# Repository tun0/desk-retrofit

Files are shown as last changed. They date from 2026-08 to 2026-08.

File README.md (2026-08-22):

# Jysk Slangerup standing desk — smart drive retrofit

Reverse engineering notes, design decisions and firmware for replacing the
control of a **Jysk Slangerup** electric height-adjustable desk.

The original complaint: the up/down buttons switch the motor on at full
voltage, so the desk jolts into motion. The goal is soft start/stop under
programmatic control, with height presets as a later phase.

This document is the project's memory. It records not just the final design
but the measurements it rests on, the alternatives considered, and — deliberately —
the wrong turns, because several conclusions here are only correct in light of
an earlier mistake.

---

## 1. The desk as found

### 1.1 Documented facts

From the JYSK manual (rev. 1, 22.06.2022; item numbers 3601130, 3601131,
75668001, 75672001, C123681):

| Property | Value |
|---|---|
| Height range | 68–118 cm |
| Max load | 40 kg |
| Speed | ~25 mm/s, load dependent |
| Duty cycle | 10% at 50% max load, or 2 min continuous |
| Operation | Micro switches |
| Anti-collision | **Not listed** (JYSK's SVANEKE model does advertise it) |
| Manufacturer of record | 2-connect ApS, Ikast, Denmark |

Essentially nothing else is publicly documented. 2-connect is a furniture
trading and sourcing company rather than an electronics designer, so they are
the CE-responsible party and the parts are unbranded OEM. There is no control
box model number, no wiring diagram, no service manual, no aftermarket
replacement. The Machinery Directive technical file is only available to
national market-surveillance authorities, not the public.

**Conclusion: everything below was measured, not looked up.**

### 1.2 Physical layout

- **Single motor**, permanently attached to one leg, driving the second leg
  through a shaft. Both columns are mechanically locked together, so one
  position measurement is authoritative for the whole desk.
- **No separate control box.** The electronics — such as they are — live in
  the motor housing. Only two cables exist: PSU → motor housing, and a
  4-conductor cable between the motor housing and the handset.
- The handset enclosure contains two rocker microswitches and nothing else.

### 1.3 Power supply

Label reads:

```
Input:  AC 100-240V  50/60Hz  1.5A
Output: DC 29.0V  1.8A  52.2W
```

The 1.8 A rating turns out to be one of the most important numbers in the
project — see §2.4.

### 1.4 The 4-conductor cable

Terminals on the motor housing, left to right: **red, yellow, white, grey**.

| Conductor | Connects to |
|---|---|
| red | UP rocker only |
| yellow | both rockers |
| white | both rockers |
| grey | DOWN rocker only |

Two shared conductors, one unique conductor per rocker, three terminals per
rocker. That topology is the signature of **two SPDT changeover switches
sharing a common pair** — the minimal H-bridge you can build from two rockers.

### 1.5 The connector

**Molex Mini-Fit Jr., 4.20 mm pitch, 4 circuits, dual row (2x2).**

Identified by caliper, recorded here because the pitch is genuinely awkward to
measure on a moulded housing with recessed cavities, and a first attempt at
buying an extension cable got the wrong part.

Two measurements, and how they combine:

| Measurement | Value |
|---|---|
| Terminal centre-to-centre (pitch), approximate | ~4 mm |
| Outer edge to outer edge across two adjacent cavities | 7.7 mm |

The second is the reliable one — flat outside faces, a longer span, so a
smaller relative error. It equals **one pitch plus one cavity width**:

```
7.7 mm  =  4.2 (pitch)  +  3.5 (cavity)      → Mini-Fit Jr.   ✓
5.4 mm  =  3.0 (pitch)  +  2.4 (cavity)      → Micro-Fit 3.0  ✗
```

Micro-Fit was the initial guess — it is the usual choice for this class of
desk — but it cannot produce a 7.7 mm span. For reference, a Micro-Fit 3.0
dual-row 4-circuit part measures 9.65 mm along the row axis against 6.65 mm
for the 2-circuit version; the 3.00 mm difference is exactly one pitch.

Family identification by pitch, for future reference:

| Pitch | Family | Current/circuit |
|---|---|---|
| 2.00 mm | Milli-Grid | low |
| 2.50 mm | Nano-Fit | ~6.5 A |
| 3.00 mm | Micro-Fit 3.0 | 5.0 A |
| 3.50 mm | Ultra-Fit | ~9 A |
| **4.20 mm** | **Mini-Fit Jr.** | **9.0 A** |

9 A per circuit is wildly over-specified for 1.8 A — normal for a furniture
OEM buying whatever was cheap and available.

Quick sanity check without calipers: Mini-Fit Jr. *is* the ATX family. The
4-pin 12V CPU plug on any PC power supply is the same connector.

### 1.6 Pinout and polarity

Measured on the **5557 receptacle** — the half with the *movable* thumb latch,
holding female sockets. The 5559 plug has the fixed catch that latch grabs.

```
Receptacle (5557, female sockets, movable latch)
viewed INTO the mating face, latch uppermost:

        ─── latch ───
      ┌───────────────┐
      │  [ 1 ] [ 2 ]  │   motor pair
      │  [ 3 ] [ 4 ]  │   supply pair
      └───────────────┘

  1 = motor          3 = supply +
  2 = motor          4 = supply -
```

The plug, viewed into *its* mating face, is the left-right mirror of this.
Never carry a "left and right" description across from one half to the other.

> **This numbering matches Molex's own, confirmed against the real sales
> drawing (SD-5557-003, also cited in `NETLIST.md` for the symbol pin
> order).** Its "CIRCUIT SIZE LAYOUT" table shows circuits 1/2 in the row
> nearest the latch and 3/4 in the row away from it, viewed into the mating
> face with the latch uppermost — the identical reference frame and
> assignment used above. The housings themselves still carry no legible
> moulded numbers, so this was derived from the drawing's orientation
> reference, not read off the part; a pre-made cable assembly could still
> use different circuit numbers internally, so don't assume one matches
> without checking.

Even with the numbering confirmed, **mark the connector physically**: a
dab of paint or nail varnish on the MOT_A cavity. Then the
mark is the definition and no orientation reasoning is ever needed again. The
housings are polarised, so the box itself cannot be mated the wrong way round.

**Polarity, measured:**

| Applied | Result |
|---|---|
| 3→2 and 4→1 (circuit 2 positive) | **UP** |
| 3→1 and 4→2 (circuit 1 positive) | **DOWN** |

**Naming convention used throughout this project:**

> **MOT_A** is the conductor that must be **positive to raise** the desk =
> circuit 2.
> **MOT_B** = circuit 1.

Defining it this way makes the schematic correct by construction, so the only
project-specific fact to remember is which circuit MOT_A is.

**On wire colours — not needed.** The colours in §1.4 did one job: deriving
the rocker topology. Everything downstream works in circuit numbers, because
the box mates with connectors rather than cutting into the cable, so a
conductor's colour mid-run never comes up. The connector end also carries a
moulded protector sleeve, so the colours are not visible there anyway.

For the record, the mapping is *predicted* but unconfirmed: red is the UP
rocker's common and the rockers rest on NC → V+ (§2.4), so red goes negative
while raising, making **red = circuit 1 (MOT_B)** and **grey = circuit 2
(MOT_A)**. If it is ever wanted, it can be had without opening the handset:
the colours are visible at the motor housing terminals, so continuity from a
housing terminal to a connector pin gives the mapping with the cable still
installed.

**Re-identification recipe.** The numbering is a convenience, not a
dependency — every fact above is re-measurable in about five minutes with
nothing but a multimeter:

| Step | Measurement | Tells you |
|---|---|---|
| 1 | ~2.5 Ω across a pair | that pair is the motor winding |
| 2 | ~29 V across the other pair (powered) | supply pair; DC volts gives + and − |
| 3 | Park at the **bottom** stop, diode mode across the motor pair | the conductor reading ~0.6 V with the **red** probe on it is **MOT_A** (positive raises) |

Step 3 works because at the bottom stop the limit switch is open and its
bypass diode passes only the escape direction, which is up.

---

## 2. Measurements and what each proved

Every measurement below was taken with mains disconnected unless noted.

### 2.1 Which pair is which

With the handset assembly disconnected:

- ~**30 V** across one pair → these are the supply rails, routed up to the handset.
- ~**2.5 Ω** across the other pair → this is the motor winding, routed up and back.

A relay coil at 29 V would read hundreds of ohms to low kilohms. 2.5 Ω can
only be a winding. **This proved the rockers carry full motor current and that
no controller exists anywhere in the desk.**

### 2.2 Isolation

- Supply negative to either winding terminal: **< 1 V**, and **open** on the
  resistance range.
- All conductor combinations open except the 2.5 Ω winding pair.

This ruled out either winding end being permanently tied to a rail — which
would have shorted the supply on the first press of a naive H-bridge retrofit.

### 2.3 End stops

Diode mode across the winding pair, measured at the motor-side terminals:

| Position | Reading |
|---|---|
| Mid-travel | near zero both directions (the winding) |
| Bottom stop | **0.6 V one way, OL the other** |
| Top stop | same behaviour, mirrored |

This identifies **diode-bypassed limit switches** — a normally-closed
microswitch at each end of travel with a diode across it, in **series** with
the winding. At a limit the switch opens: one polarity is blocked entirely,
the other passes through the bypass diode so the desk can drive away from the
stop. Two switches, two diodes, still only two conductors down the leg.

Consequences:
- The desk cannot be driven past either extreme, in hardware, regardless of
  firmware. This is inherited for free by any retrofit.
- Homing is clean: drive down until current collapses to zero. That is the
  switch opening at a repeatable mechanical position.

### 2.4 Rest state and current

With both rockers in neutral, **three of the four contacts read shorted**, to
the **positive** rail. Both rockers sit on their NC contacts, tying both
winding ends to V+. That is dynamic braking, and it explains why the desk
stops as abruptly as it starts.

Locked-rotor current would be 29 V ÷ 2.5 Ω ≈ **11.6 A** — but the supply is
rated 1.8 A. The PSU current-limits long before the winding sees anything like
that. Practical consequences:

- The supply is already acting as the current limiter and, incidentally, as
  the collision protection. Jam the desk and it drops into limit and stalls
  rather than drawing 12 A.
- **Do not casually fit a bigger PSU.** That current limit is load-bearing
  safety on a frame with no other protection, and the motor's thermal rating
  was chosen around it.
- A sanity check supports this: lifting ~60 kg at 25 mm/s is ~15 W mechanical,
  which through a spindle drive lands near 40–50 W electrical. The desk runs
  close to the supply limit under load, which is exactly what the manual's
  "speed depends on load" is describing.

### 2.5 The as-found circuit

```
SW3 (UP rocker, SPDT):
    NC ── V+
    NO ── V−
    COM ── [LIM_top ∥ D_down] ──┐
                                 │
                                (M)
                                 │
SW4 (DOWN rocker, SPDT):         │
    NC ── V+                     │
    NO ── V−                     │
    COM ── [LIM_bot ∥ D_up] ─────┘
```

At rest both rockers sit on NC (→ V+), tying both winding ends to the
positive rail — that's the brake state. Pressing a rocker moves its COM
to NO (→ V−) instead, which is what drives the motor.

Not kept as a separate schematic file — this circuit is fully captured by
the measurements above and the diagram, and the stock wiring is unmodified
in the chosen design (§4).

---

## 3. Design evolution

Four designs were considered in sequence:

| | Design | Outcome |
|---|---|---|
| 3.1 | ESP32 + integrated H-bridge IC | rejected on voltage headroom |
| 3.2 | Relay direction + low-side FET PWM | adopted as the drive topology |
| 3.3 | In-line interceptor with 3-pole transfer relay and automatic fallback | good design, dropped as over-complex |
| 3.4 | **Simple in-line drive** | **chosen** |

> Why each of the first three lost, and what would be worth keeping if any
> were revived, is in **`APPENDIX.md` §5**. Several were reasonable at the time
> and became obsolete only when a later measurement changed the picture.

### 3.4 Simple in-line drive — **CHOSEN**

Same in-line position, no transfer relay, no automatic fallback. The board
owns the winding permanently. Reverting is physical:

```
motor — box — handset      becomes      motor — handset
```

39 components instead of 51. Dropping the transfer also deleted the clamp
diodes: with no transfer relay, 29 V can never appear on the handset
conductors, so there is no transition window to protect against.

---

## 4. The chosen design

Schematic: `desk.kicad_sch` / `.pdf`.

### 4.1 Topology

```
PSU 29V ────────┬── VSW rail
                │
                ├── buck ── +5V ── ESP32
                │
         [K1]───┴────[K2]        two SPDT relays, NC→VSW, NO→MRET
          │           │
          └─ winding ─┘      via limit switches in the leg
                │
              MRET ──[Q5]── GND    low-side PWM
                │
              [D1] freewheel to VSW
```

### 4.2 Relay truth table

`MOT_A` = circuit 2, positive to raise (§1.6). `MOT_B` = circuit 1.

| K1 | K2 | Result |
|---|---|---|
| off | off | both winding ends on VSW → **brake** (matches OEM rest state, and is the boot state) |
| **on** | off | MOT_B to return, MOT_A stays positive → **UP** |
| off | **on** | MOT_A to return, MOT_B stays positive → **DOWN** |
| on | on | both ends on MRET → coast if Q5 off, brake to ground if on |

No combination shorts the supply.

The signal chain therefore runs `DIR_A → U3 → Q3 → K1 = up` and
`DIR_B → U3 → Q4 → K2 = down` (same chip, different gate units - see
NETLIST.md), which is what `relay_up:` and `relay_down:` in
`desk.yaml` are wired to. The current sensor sits in the K1 (MOT_B) leg; either
leg works, since it only needs to be inside the freewheel loop.

### 4.3 The handset

Permanently removed from the motor circuit. The board feeds it **3.3 V** and
reads the rockers as dry contacts — high at rest through the OEM NC contact,
low when pressed. Same cable, same connectors, different job. The tactile
up/down survives alongside the screen.

### 4.4 Current sensing

An **ACS712ELCTR-05B** sits in the motor leg, *not* in the FET return (switched
from the ACS724-5AB this design used earlier — see §6.5/§6.6; same Hall-effect
family, pin-identical, chosen for real stock availability). With low-side
chopping the FET only carries current during the on-time; freewheel current
bypasses it entirely, so a low-side shunt would read a chopped fraction and
need synchronous sampling. In the motor leg the sensor is inside the freewheel
loop and reads true motor current continuously.

Its output is centred at 2.5 V, 185 mV/A (Allegro's own datasheet figure for
this exact part), reaching ~3.4 V at the full ±5 A range - over a comfortable
ADC margin, so R1/R2 (10k/20k) divide it down to a ~2.3 V max. **ISENSE must
be on ADC1** — ADC2 is unusable while WiFi is active.

### 4.5 Failsafe layer

- **Boot state.** R8/R9/R10 hold all three drive lines at "off" before firmware
  runs. These *must* sit on non-strapping GPIOs — on the classic ESP32 avoid
  GPIO0, 2, 12 and 15, since a pull resistor there fights the bootloader and
  GPIO12 pulled high selects the wrong flash voltage. The S3's strapping set
  differs; the principle holds.
- **Watchdog.** A 74HC123 retriggerable monostable (~250 ms) gates all three
  drive lines through a 74HC08. The ESP32 must keep kicking it. This sits
  **downstream of the MCU** deliberately: LEDC PWM keeps running in hardware
  after a firmware hang, so stopping PWM in software is not a safety measure.
- **Sequencing.** Relays change state only with Q5 off and current decayed
  (~50 ms). Switching contacts under a couple of amps of inductive DC is how
  relays weld, and a welded direction relay on a desk is a genuinely bad
  failure. On a watchdog trip this holds automatically: Q5 turns off in
  microseconds while relays take milliseconds to release.
- **Coast is safe.** Loss of drive leaves the desk where it is, because the
  spindle is self-locking. This is why the stock desk isn't dangerous despite
  having no electronics at all.
- **Duty cycle.** Enforce the manual's 10% / 2-minute limit in firmware.
  Thermal damage is the boring failure mode.
- **Travel timeout.** Full range is 500 mm at 25 mm/s, so anything over ~25 s
  of continuous drive is a fault.

---

## 5. Corrections made along the way

Recorded because several later conclusions only make sense in light of these.

1. **"No anti-collision implies no current sensing."** Too quick. If the desk
   had used stall detection at the end stops, it would have needed current
   sensing after all. Resolved by finding passive diode-bypassed limit
   switches — but the inference was unsound until then.
2. **Predicted the wrong diode-test result.** Expected "winding one way, diode
   the other". Wrong: the switch and its bypass sit in *series* with the
   winding, so at a limit one polarity is blocked entirely. The measured
   0.6 V / OL is what the series arrangement predicts.
3. **Recommended BTS7960 / VNH5019 on current headroom alone.** Both are out
   of voltage spec at 29 V (BTS7960: 5.5–27.5 V; VNH5019: 5.5–24 V). They
   survive 40 V+ as absolute maximum, but "probably fine" is not what should
   be holding up a desk.
4. **"Size the bridge for 12 A stall."** Wrong — the PSU current-limits at
   1.8 A, so the winding never sees locked-rotor current. This also reframed
   the supply as the existing collision protection.
5. **"Losing brake removes protection."** Overstated, and inconsistent with
   the self-locking spindle noted elsewhere. The brake does stop-precision
   work, not safety work.
6. **Wired NC to V− in the first `desk_original` schematic.** The measurement
   (three contacts shorted, to the positive rail) says NC → V+. Caught only
   when the netlist was rendered as a connectivity graph; the written note and
   the drawing had disagreed silently.
7. **Ran literal power rails across the schematic sheet.** Intended to remove
   "islands"; produced a picket fence of metre-long ground verticals instead.
   Local GND and rail symbols are the conventional idiom precisely because
   they avoid this. The real problem was that *signals* were labelled rather
   than wired.
8. **Planned an "ESP32 devkit + display" (CYD).** This board lives under the
   desk, not somewhere a display is ever seen, so U1 is a bare
   ESP32-S3-DevKitC instead. A display, if ever wanted, would be a separate
   peripheral mounted on the desk itself, not part of this board.
9. **Specified Q5 as IRLB8721.** Caught by an external review, not by this
   project's own process — the schematic still had it after the part was
   supposedly already swapped. IRLB8721's 30 V VDSS doesn't clear the 29–30 V
   rail once flyback clamping is accounted for; fixed to IRLZ44N (55 V). See
   §6.2.
10. **Assumed hand-wired perfboard was the assembly plan.** Reasoning at the
    time: this design is all through-hole specifically because there's no
    reflow equipment, and a fab-house PCB order felt like overkill for a
    one-off — so point-to-point perfboard wiring, guided by a generated
    wiring table, looked like the natural fit. Reversed once that wiring
    table turned out to need far more jumpers than expected, concentrated
    around locally dense ICs rather than anything structural — a strong
    signal that hand-wiring reliability, not layout, was the actual risk.
    A real 2-layer board (still hand-soldered, still through-hole — see
    §6.5) routes those same nets with zero jumpers once an autorouter can
    place traces on both layers, so it was worth doing even without a
    fab-house order: milled at home from a standard 70×100mm pre-cut
    copper-clad blank instead of ordered or hand-wired. See
    `schematics/desk.kicad_pcb` and its commit history for the design
    itself.

---

## 6. Bill of materials

Rough EUR incl. BTW, Netherlands. Prices are budgeting figures, not quotes.

| Item | Note | Cost |
|---|---|---|
| ESP32-S3-DevKitC | bare devkit, no display — see §5 | €5–15 |
| 2x SRD-05VDC-SL-C relay | bare relay, not a driver-included module — this design drives the coil directly, see NETLIST.md Drive section | €3–5 |
| 2x 2N7000 MOSFET | relay coil drivers (Q3/Q4), TO-92 — through-hole | €1–2 |
| IRLZ44N MOSFET | logic-level, 55V — see §6.2 | €1–2 |
| BC337 + BC327 | discrete gate driver push-pull — see §6.2 | €1–2 |
| 74HC123 + 74HC08 | watchdog and gating | €1–3 |
| SB560 Schottky | freewheel | <€1 |
| 2x 1N4148 | relay coil flyback diodes (D2/D3), DO-35 | <€1 |
| ACS712ELCTR-05B (bare) + SOIC-8→DIP-8 adapter | bidirectional, 5A — see §4.4/§6.5; switched from the ACS724xLCTR-05AB this design used earlier for real stock availability (pin-identical, see §6.6); the Pololu carrier is dropped either way, its 2 caps (C2/C3) now on the main board instead; or 10 mΩ shunt + INA240, similar cost | €2–5 |
| LM2576HVS-5.0 buck | **must** be the true HV variant (60V input) — see §6.1/§6.5; SMD (TO-263-5), not the THT part this design used earlier, which proved unsourceable at hobbyist quantities | €6–9 |
| TVS 33 V bidirectional | D4 — no fuse fitted, see §6.1 | <€1 |
| Passives | resistors, caps | €4–8 |
| 4x 2-position screw terminal | 2.54mm pitch, board-side termination (TB1, TB2, TB4, TB5) — see §6.4 | €2–4 |
| Mini-Fit Jr. housings + terminals | 2 mating pairs, each now on a short pigtail off the board rather than a board-mount connector — see §6.4 | €3–6 |
| PCB blank, 70×100mm pre-cut copper-clad (2-layer) | milled, not fab-house ordered — see §6.5; SHOPPING_LIST.md flags this as still needing a specific supplier | €5–10 |
| **Total** | | **€25–100** |

Phase 2 adds ~€15–25 for a VL53L1X carrier and bracket. Sourcing detail
below (§6.6).

### 6.1 Voltage, not current, is the constraint

The rail is 29 V nominal, 30 V unloaded. Anything in the motor path or the
buck input needs headroom above that. Common traps:

- BTS7960 / IBT-2: spec'd 5.5–27.5 V. Out of spec.
- VNH5019: 5.5–24 V. Out of spec.
- MP1584 / Mini-360 buck modules: top out ~28 V. Marginal at best.

No fuse is fitted (there was one in early drafts, `F1`). The wall supply
already current-limits at 1.8 A — that limit is this design's only collision
protection, already relied on elsewhere (§4.4, `CLAUDE.md`'s own hard
invariants) — so a fuse adds little on top of it while being one more
embedded part to replace if it ever blows. The OEM desk never had one
either. D4 (33 V bidirectional TVS) stays.

### 6.2 Q5: voltage rating first, then the gate driver

**Q5 is IRLZ44N (55 V), not IRLB8721 (30 V).** The IRLB8721 is a common
default for "logic-level MOSFET," but its 30 V VDSS doesn't clear this
29 V nominal / 30 V unloaded rail — at PWM turn-off the freewheel diode
clamps the drain to VSW plus a diode drop, putting it at or over absolute
maximum every cycle. Substitution criterion for any replacement: check
**Qg and VDSS**, not Vgs(th) — plenty of parts marketed as "logic-level"
still top out at 30 V.

The gate driver still isn't optional: at 3.3 V Vgs a logic-level MOSFET is
only partially enhanced, and at 20 kHz that's how you cook a part that
would otherwise dissipate under 0.1 W. This design drives Q5 from a
discrete BC337/BC327 push-pull (not an IC — see `schematics/gen/symbols.py`),
fed 5 V through the AND gate output. Avoid the ubiquitous IRF520 "MOSFET
trigger" modules — that FET isn't logic-level at all.

### 6.3 K1/K2 are bare relays, not a driver-included module

**This design drives the coil directly** (Q3/Q4 discrete transistor
switches, D2/D3 flyback diodes — see NETLIST.md's Drive section), not
through a prebuilt "2-channel relay module" board. Those Arduino-kit
modules already include their own opto-isolated input, driver transistor
and flyback diode, which would make Q3/Q4/D2/D3 redundant rather than
complementary if one were used here — don't substitute one in without
also removing this board's own driver circuit. What to check when buying
the bare relay itself:

- **Coil voltage** — must be 5 V; this design's coil drive assumes it, and
  a 12 V coil would draw roughly half the current for the same drive
  voltage, undersaturating the relay.
- **Contact rating** — typically 10 A 250 VAC / 10 A 30 VDC. Your 29 V is right
  at that DC limit; acceptable only because contacts are cold-switched
  (§Sequencing/hard invariants — relays only change state with the FET
  off and current decayed).
- **Pinout** — EN50005/"Form C" (the real Kicad symbol this design uses,
  `Relay_SPDT`) is the common footprint for this class of relay; verify
  before assuming a drop-in substitute matches pin-for-pin.

### 6.4 Connector parts (Mini-Fit Jr., 4 circuit dual row)

| Part | Molex no. | Legacy |
|---|---|---|
| Receptacle housing (holds female terminals) | `39-01-2040` | 5557-04R |
| Plug housing (holds male terminals) | 5559 series, 4-circuit | 5559-04P |
| Female crimp terminal | 5556 | |
| Male crimp terminal | 5558 | |

**Wire-to-wire pairs a 5557 receptacle with a 5559 plug.** Datasheets for the
5557 list 5566 and 5569 as mating housings — those are *PCB headers*, not the
wire-to-wire half. That is the most likely explanation for the first wrong
order, alongside Molex's naming: a "receptacle housing" holds female terminals
while a "plug housing" holds male pins, and the plug is the part that inserts
into the receptacle. Order by the terminals, not by the shape you are looking
at, and check the datasheet drawing.

The retrofit box needs a **5559 plug on one end and a 5557 receptacle on the
other**, so it drops into the existing cable run in only one orientation.

Make up a short 5557-to-5559 **coupler** at the same time and tape it inside
the leg. That is the one-minute revert, and it is worth doing while the parts
and crimp tool are already on the bench rather than at an awkward moment.

Because this is the ATX family, a PC 4-pin 12V CPU extension is mechanically
correct and costs a few euros. Two cautions: verify the pinout is
straight-through 1:1 rather than crossed, and PC cables use stiff 18 AWG that
may not sit well in a desk-sized strain relief. Crimping your own in 20 or
22 AWG gives a tidier result; 2 m at 1.8 A is a couple of hundred millivolts
round trip either way.

Build any extension by **matching wire colours end to end** rather than
trusting circuit numbering. One reversed pair swaps the rails.

**The board itself doesn't carry a Mini-Fit connector at all.** Each side
(motor housing, handset) terminates on the board in a 2-position screw
terminal instead (TB1, TB2, TB4, TB5 — 2.54mm pitch, solders straight onto perfboard,
no crimp tool needed for board assembly). A short pigtail, crimped
separately on the bench, carries each pair from its screw terminal to the
actual Mini-Fit half (still needed, still built exactly as described
above) that mates with the cable. One extra connection point per circuit
versus terminating the Mini-Fit directly at the board edge, traded for
never needing a crimp tool during board assembly or rework.

### 6.5 This design is deliberately all through-hole

A hand-soldered, self-milled 2-layer PCB (`schematics/desk.kicad_pcb`,
sized to a standard 70×100mm pre-cut blank), not a fab-house order and not
raw perfboard either — but the reason for through-hole-only still holds
regardless of which of those three it ends up being: no reflow equipment.
Every substitution should preserve that, not just match electrically.
Substitution criterion is the **package**, not just the part:

| Part | Through-hole option |
|---|---|
| 74HC123 | `74HC123N` / `SN74HC123N`, DIP-16, socketed |
| 74HC08 | `SN74HC08N`, DIP-14, socketed |
| BC337 / BC327 | TO-92 (already through-hole) |
| IRLZ44N | TO-220 |
| 2N7000 | TO-92 |
| SB560 | DO-201AD axial |
| TVS 33 V | `P6KE33CA` or `1.5KE33CA`, axial |
| Coil flyback | `1N4148`, DO-35 |
| SRD-05VDC-SL-C relay | bare relay, TO-5-ish THT (EN50005/Form C) |
| ACS712 | bare SOIC-8 chip on a generic SOIC-8→DIP-8 adapter, socketed like U1 |
| ESP32-S3-DevKitC | devkit module, socketed with 0.1" pin headers |

Every DIP part on this board is socketed, not just U1/U4 as originally
planned - noticed missing from the shopping list only after seeing a
render (see conversation), added for all of U2/U4/U3 once caught. Worth
it specifically because this board is hand-milled, not a plated-through-
hole fab board - pads are more fragile under a desoldering mistake here
than on a normal PCB, and sockets cost pennies.

**U5 (buck regulator) is the one deliberate exception.** The true
through-hole HV buck (`LM2596HVT`/`LM2576HVT`, TO-220-5) turned out to not
practically exist at hobbyist quantities anywhere checked — Reichelt, TME,
Mouser, Farnell direct, and Farnell-via-sinuss.nl all came up empty or
unconfirmed for the T-suffix part specifically (see conversation). The
real, in-stock option is `LM2576HVS-5.0/NOPB`, S-suffix, **TO-263-5 SMD**.
This doesn't violate the "no reflow" reasoning, though: TO-263-5 is 5
large gull-wing leads at roughly TO-220 pitch plus a thermal tab, one of
the more hand-solder-friendly SMD packages that exists — no hot air or
reflow needed, just a bit more dwell time on the tab. Checked directly
against TI's own datasheet: TO-220-5 and TO-263-5 share an identical pin
table, so this was a footprint-only change, no rewiring.

ACS712 (`ACS712ELCTR-05B`, §4.4) is SOIC-8, not through-hole itself — what
keeps the board through-hole is whatever it's mounted on, same reasoning
as U1. This design used the ACS724xLCTR-05AB before switching to ACS712
(same Hall-effect family, verified pin-identical against both datasheets
directly, pin-for-pin — not assumed from the similar part number or a
misleadingly-named KiCad library symbol, see conversation) purely because
the ACS724 bare chip proved nearly unsourceable, while ACS712ELCTR-05B is
in real stock at three-plus suppliers already in rotation for this
project. Either way, mounting the bare chip on a generic SOIC-8-to-DIP-8
adapter (0.3"/7.62mm row spacing, already in inventory) instead of a
ready-made carrier (Pololu, in this design's earlier revisions) drops two
things that carrier provided for free: a 0.1uF VCC bypass cap and a 1nF
FILTER-to-GND cap, both confirmed against Allegro's own ACS712/ACS724
application circuit (identical circuit on both parts' datasheets, not
just the Pololu board). Both are now discrete parts on the main schematic
instead (C2, C3) - see NETLIST.md.

### 6.6 Sourcing (Netherlands)

Ruled out, with reasons, so they are not re-evaluated:

- **Digikey** — ~€25 shipping on small orders.
- **Farnell direct** — private-customer orders need a write-in request
  (email/fax/post) and prepayment, not normal checkout, on top of the €50
  minimum. **sinuss.nl** is a live, working Farnell/element14 private
  reseller for NL/BE (confirmed directly, unlike muxtronics.nl's own
  Farnell-intermediary service, which is dead) — usable if a Farnell-only
  part is unavoidable, but at a real price premium (30–50%+ over Farnell's
  own business pricing, confirmed directly) - not worth it for anything
  also stocked at Reichelt/TME.

Working pattern, per actual checked availability (see conversation for
the full supplier-by-supplier matrix):

- **Reichelt** — jellybeans and basic semis: resistors, caps, diodes
  (1N4148, SB560, TVS), 2N7000, IRLZ44N, `74HC123N` (also at Mouser and
  Farnell direct - TME is the actual outlier here, not Reichelt), screw
  terminals.
- **TME** — `SN74HC08N`; the `LM2576HVS-5.0/NOPB` SMD buck (§6.5 - the
  through-hole HV buck isn't practically available anywhere at hobbyist
  quantities); the SRD-05VDC-SL-C's real named equivalent, Omron
  `G5LE-1-5VDC` (5V coil, SPDT/Form-C, 10A/250VAC-30VDC — exact spec
  match, the bare Songle part itself is a module-market item most proper
  distributors don't stock discretely); and `ACS712ELCTR-05B` — confirmed
  in stock by hand after automated checks kept giving contradictory
  stock figures for it. Between this and the buck/relay, TME covers
  enough that **Mouser isn't needed at all** for the current design.
- **Modules** (ESP32 devkit, etc.) — TinyTronics (Ede), Kiwi Electronics,
  Opencircuit (Zaandam) or Antratek.
- **PCB blank** (70×100mm copper-clad) — not found at any of the above;
  expect to need a hobby/eBay/AliExpress source, as originally
  anticipated.

Substitutes worth recording:

- **IRLZ44N** → any 55–60 V logic-level N-channel in TO-220. Check **Qg and
  VDSS**, not Vgs(th) — see §6.2.
- **74HC08** → 74HC00 with inverted logic, or 74HC11 triple 3-input AND.
- **ACS712** → 10 mΩ shunt + INA240 (in the motor leg, not the FET return -
  same reasoning as §4.4), but INA240 is SOIC-8 and needs a breakout too -
  same treatment as ACS712 itself (§6.5), not a way to avoid one.

---

## 7. Firmware

ESPHome, with motion control in a custom external component.

Pure YAML cannot do this safely. Three reasons, all in the safety path:

- The watchdog kick must come from the control loop, not a timer. ESPHome's
  `interval` runs in the cooperative main loop, which WiFi work can stall for
  hundreds of ms. Solving that with a hardware LEDC pulse is worse — it keeps
  kicking through a hang, making the monostable decorative.
- Relay sequencing is a small state machine with real timing constraints.
- `adc` sensors poll on the order of seconds. Useless for collision detection.

What ESPHome earns: OTA, logging, web server, Home Assistant integration, and
LVGL for the screen. Inheriting `cover::Cover` makes the desk a first-class HA
entity with open/close/stop/position and no glue.

### 7.1 Structure

```
config/
  desk.yaml
  my_components/
    desk/
      __init__.py      (empty)
      cover.py         config schema + codegen
      desk_cover.h
      desk_cover.cpp
```

`cover.py` declares the YAML keys and emits C++ setter calls into the
generated `main.cpp`. Anything configurable goes there; anything fast goes in
the `.cpp`.

### 7.2 Control loop

A FreeRTOS task pinned to **core 0**, ticking at 200 Hz via `vTaskDelayUntil`.
WiFi lives on core 1 and cannot stall it. Each tick reads current, runs the
state machine, updates PWM duty, and *then* kicks the watchdog — after a
completed iteration, never on a timer.

States: `IDLE → SETTLING → RAMPING → RUNNING → STOPPING → IDLE`, plus a latched
`FAULT`. Relay writes are legal in `IDLE` only, and every direction change
routes through `SETTLING`. Enforcing that structurally is what stops a future
refactor quietly switching a relay under load.

Starting parameters: 20 kHz PWM, 500 ms ramp up, 300 ms ramp down, 50 ms
settle. Tune the ramps by feel.

### 7.3 To fill in

- `read_current_()` is implemented (both IDF 4.x `adc1_get_raw` and 5.x
  `adc_oneshot_read` paths, selected via `ESP_IDF_VERSION` - see
  `desk_cover.cpp`), but not yet compiled or flash-tested against real
  hardware. Why the YAML specifies `esp-idf` rather than Arduino at all:
  ESPHome's `adc` sensor is far too slow for a 200 Hz control loop.
- Relay `inverted:` flags follow this board's own direct-drive polarity
  (AND-gate through the 2N7000 coil drivers — see §6.3/NETLIST.md's Drive
  section), fixed by this design, not something a swappable module would
  determine.

**Flash with the motor unplugged first.** Watch the log and the current sensor
before anything can move.

---

## 8. Phase 2 — position feedback and presets

Phase 1 deliberately has no absolute position sensing. Presets need it.

> Full option analysis, including mounting constraints, range limits and the
> approaches that will not work, is in **`APPENDIX.md` §2**. The summary below is
> the decision, not the reasoning.

### 8.1 Direction

Leading candidate is a **VL53L1X time-of-flight sensor** aimed at the fixed
foot plate. Absolute encoding is not worth paying for, because the bottom
limit switch already gives a repeatable mechanical reference detected by
current collapse — one trip down re-homes the desk.

> Full analysis — mounting constraints, the range limit that could sink it,
> incremental optical and magnetic alternatives, commutator ripple counting,
> and why an IMU cannot do this — is in **`APPENDIX.md` §2**.

**Board prep done now, ahead of the actual build (see conversation):**
SDA/SCL break out to a real connector, `TB3`, a 5th screw terminal of the
same type as TB1, TB2, TB4, TB5, fully routed and DRC-clean. +3V3/GND for the sensor
don't get their own terminal - land a second wire under each of `TB2`'s
own two screws instead (it already carries +3V3/GND to the handset; check
that this terminal's rising-clamp accepts two wires per screw before
counting on it - a dedicated second terminal, `TB6`, was tried and
dropped once TB2-sharing made it unnecessary).

**SDA/SCL are on GPIO38/GPIO41, not GPIO12/GPIO13.** The original choice
(physical pins 18/19 on U1's footprint) turned out to sit in a part of the
board that's already at real copper capacity - neither Freerouting nor
careful manual routing could get a single track out from there, regardless
of where TB3 sat. GPIO38/41 (physical pins 35/38) sit immediately next to
DIR_A/DIR_B/PWM (pins 36/37/39), GPIOs that already route successfully
from that same neighborhood - moving to them, and relocating TB3 close by
(rotated 90° to fit the only free space in that corner), routed cleanly on
the first attempt after that. Neither is strapping/PSRAM-reserved/native-
USB, same constraints as the original choice. Firmware should target
GPIO38 (SDA) and GPIO41 (SCL) for this reason - not the GPIO12/13 an
earlier version of this section named.

### 8.2 Data worth logging from day one

Current against time for a full travel in each direction, and coast distance
after cutoff at various speeds. That's exactly the calibration data phase 2
needs, and you get it free by using the desk. If commutator ripple turns out
to be cleanly visible on the current-sense trace, the cheapest option may be
the one already built.

---

## 9. Open questions

- Exact position of the limit switches inside the leg is inferred from
  behaviour; the leg was never opened.
- The polarity convention at each limit (which probe orientation gave 0.6 V)
  was not written down. Two-minute remeasure, needed before wiring the relays
  so "up" is actually up.
- Wire colour to circuit number is predicted but unconfirmed (§1.6), and is
  **not required** for the build — noted only for completeness.
- Which of yellow / white is supply positive was never recorded. Also not
  required: circuits 3 and 4 are identified on the connector itself.
- The housings carry no legible moulded circuit numbers, but §1.6's numbering
  is now confirmed against Molex's own SD-5557-003 drawing, not just this
  file. Still worth marking the MOT_A cavity with paint so the physical part
  carries the convention directly, rather than requiring a lookup.
- ERC has been run (`kicad-cli sch erc`): 127 violations, all triaged as
  either documented gaps (unused MCU pins, U2/U3 spare units, SDA/SCL
  pending Phase 2) or artefacts of this design's power-flag/embedded-symbol
  conventions — no structural defects found.

---

## 10. Files

| File | Purpose |
|---|---|
| `APPENDIX.md` | Background, rejected alternatives, phase-2 analysis — not required to build |
| `CLAUDE.md` | Project context for Claude Code |
| `SHOPPING_LIST.md` | Purchase-ready BOM, grouped by supplier — see §6 for the narrative version |
| `schematics/desk.kicad_sch` / `.pdf` / `.svg` | **The chosen schematic design** |
| `schematics/desk.kicad_pcb` | **The chosen PCB layout** — 70×100mm, 2-layer, hand-milled (§6.5) |
| `schematics/NETLIST.md` | Connectivity reference, generated + annotated |
| `schematics/gen/` | Generator and its dependencies — see `CLAUDE.md` |
| `enclosure/shell.scad` / `.stl` | 3D-printable enclosure (single open-bottom shell) — component clearance is an estimate, see the file's own header comment |
| `my_components/desk/` | ESPHome external component |
| `desk.yaml` | Example ESPHome config |

Schematics are KiCad 7 format (`version 20230121`); KiCad 7, 8 and 9 open them.
Symbols are embedded (either hand-drawn or copied from real KiCad libraries),
so there are no external library dependencies at open-time. Regenerate with
`cd schematics/gen && make` (or `python3 sch.py`, then
`kicad-cli sch export pdf ../desk.kicad_sch`).

---

## 11. Safety notes

- Mains lives in the PSU. All work here is on the 29 V side. Do not open the
  supply.
- 29 V will not hurt you, but a dead short across it will make a mess. The
  supply can deliver 1.8 A continuously and rather more from its output
  capacitance.
- The spindle is self-locking and holds the load unpowered. This is what makes
  coast an acceptable failure mode, and it is the single assumption most worth
  re-verifying if the frame is ever changed.
- The 1.8 A supply limit is part of the safety story on a desk with no
  anti-collision. Replacing the PSU with something beefier removes protection
  the design depends on.

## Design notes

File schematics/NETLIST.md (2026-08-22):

# desk — schematic as text

Generated from KiCad's own netlist export (`kicad-cli sch export netlist`)
against the current `desk.kicad_sch`, so this reflects actual
connectivity, not the Python source. Regenerate the raw connection list (and
diff it against a saved copy, or another variant) with:

```sh
cd schematics && python3 sch.py && python3 netlist_text.py desk.kicad_sch
```

This document adds functional descriptions on top of that raw list. Kept as
a reference for understanding the circuit or rebuilding it by hand — not a
substitute for `sch.py`, which is the actual source of truth.

## Components

| Ref | Value | Notes |
|---|---|---|
| PS1 | 29V 1.8A 52W (via motor housing) | wall supply, current-limiting |
| D4 | 33V bidir | TVS, input transient protection; no fuse fitted, see README 6.1 |
| C4 | 220u 50V | input bulk cap |
| U5 | LM2576HVS-5.0 29V-5V | buck regulator, SMD (TO-263-5) - the true through-hole HV part wasn't sourceable, see README 6.5; real part is base symbol LM2596T-12, a pin-compatible non-HV placeholder for the library's own missing HV/SMD variant, see TODO.md |
| C5 | 220u 10V | +5V output cap |
| TB4 | motor pair | 2-position screw terminal; board-side termination for MOT_A/MOT_B, pigtails to J3 via J2 (no longer drawn - see Connectors) |
| TB5 | supply pair | 2-position screw terminal; board-side termination for VSW/GND, pigtails to J3 via J2 |
| TB1 | signal pair | 2-position screw terminal; board-side termination for HND_A/HND_B, pigtails to J4 via J1 |
| TB2 | power pair | 2-position screw terminal; board-side termination for +3V3/GND, pigtails to J4 via J1 |
| TB3 | ToF signal pair | 2-position screw terminal; SDA/GPIO38 and SCL/GPIO41 breakout for a future VL53L1X (Phase 2, not started - see README 8). Fully routed and DRC-clean - originally targeted GPIO12/13, moved after those pins proved unroutable, see README 8.1. +3V3/GND for the same sensor share TB2 (a second wire under each of its screws) rather than a dedicated terminal - a `TB6` for that was tried and dropped once TB2-sharing made it unnecessary. |
| U1 | ESP32 | bare devkit, no display - see README 5/6; real part is Espressif's ESP32-S3-DevKitC symbol (vendored, see Controller section) as the closest local match |
| R3 | 4k7 | HND_A series resistor (rocker divider) |
| R5 | 100k | SW_UP pull-up to +3V3 |
| R4 | 4k7 | HND_B series resistor (rocker divider) |
| R6 | 100k | SW_DN pull-up to +3V3 |
| U2 | 74HC123 250ms | monostable (retriggerable watchdog timer); real part is 74LS123, `74HC123` is a same-pinout wrapper in Kicad's library |
| R7 | 100k | U2 timing resistor |
| C1 | 2u2 | U2 timing capacitor |
| U3 | 74HC08 | triple AND gate (3 of 4 gates used); real part is 74LS08 placeholder, see TODO.md |
| R8 | 10k | DIR_A gate pulldown (boot-safe) |
| R9 | 10k | DIR_B gate pulldown (boot-safe) |
| R10 | 10k | PWM gate pulldown (boot-safe) |
| Q1 | BC337 | gate driver for Q5, NPN half of a discrete push-pull (replaces a TC4427 IC) |
| Q2 | BC327 | gate driver for Q5, PNP half of the push-pull |
| R11 | 1k | Q1/Q2 base resistor |
| Q5 | IRLZ44N | main PWM FET, low side |
| D1 | SB560 | freewheel diode |
| K1 | energized = UP (raises desk) | relay, real part Relay_SPDT (EN50005 pinout) |
| K2 | energized = DOWN (lowers desk) | relay, same part as K1 |
| D2 | flyback | K1 coil flyback diode |
| D3 | flyback | K2 coil flyback diode |
| Q3 | 2N7000 | K1 coil driver |
| Q4 | 2N7000 | K2 coil driver |
| U4 | ACS712ELCTR-05B | current sensor, in series with K1's leg; switched from ACS724xLCTR-05AB for real stock availability, checked pin-identical against both datasheets - see README 6.5/6.6. The library symbol used is literally named after this part now, no "extends" placeholder needed |
| R1 | 10k | ISENSE divider, top |
| R2 | 20k | ISENSE divider, bottom |
| SW1 | top limit | limit switch, in the leg |
| SW2 | bottom limit | limit switch, in the leg |
| D5 | allows down | SW1 bypass diode |
| D6 | allows up | SW2 bypass diode |
| M1 | 2R5 winding | motor |

## Power

Each rail is drawn as many separate flag symbols (one per tap point), not one
continuous wire — they still form a single real net each, because the
GND/rail symbols are flagged as Kicad power symbols (`(power global)`); see
`schlib.py`'s `Sym` docstring if adapting this pattern elsewhere. Confirmed
against Kicad's own netlist export, which merges them into one named net
each:

- **VSW**: D1.1, K1.12, K2.12 — the raw supply rail via the two relays' NC
  contacts and D1's anode. TB5/D4/C4/U5.1 sit on a separate, unnamed net
  (same potential, reached only through the literal-wire chain below, not
  through a VSW-flagged tap) - see Supply.
- **+5V**: C5.1, D2.1, D3.1, K1.A2, K2.A2, Q1.1, R7.1, U5.2, U5.4, U1.21,
  U2.16, U2.2, U2.3, U4.8, U3.14 — regulated 5V, from U5's OUT (pin 2) and
  FB (pin 4, tied to OUT - see Drive/Supply below)
- **+3V3**: R5.1, R6.1, TB2.1, U1.1, U1.2 — from the ESP32 board's own
  regulator (real part has two physical 3V3 pins, merged onto one net by
  Kicad's power-symbol matching even though only pin 1 is wired), not
  generated on this board; only fed out to the handset (via TB2/J1/J4) and
  the rocker pull-ups. TB2 is also the planned physical source for a
  future ToF sensor's +3V3/GND (second wire under each of its screws,
  not a separate net or terminal - see README 8.1)
- **GND**: C4.2, C5.2, C1.1, D4.2, PS1.2, Q5.3, Q3.3, Q4.3, Q2.1, R8.2, R9.2,
  R2.2, R10.2, TB5.2, TB2.2, U5.3, U5.5, U1.22, U1.23, U1.24, U1.44, U2.8,
  U4.5, U3.7

## Connectors

The board itself no longer carries a Mini-Fit Jr connector at all - see
"screw terminals" below. J3/J4 remain: both Molex Mini-Fit Jr, 4 circuit
dual row (README 1.5). Real part: Kicad's `Conn_02x02_Top_Bottom` -
row-major numbering (pins 1,2 = row 1; pins 3,4 = row 2), confirmed against
Molex's own 5557-series sales drawing (SD-5557-003).

- **J3** (in motor housing): the actual mating half for the motor housing
  cable. Wired directly to the LEG section's own motor leads and to PS1,
  not to a same-named-label match - see the note at the end of this
  document. Mates with a short pigtail off TB4/TB5 (see below), not with a
  second Mini-Fit drawn on this sheet.
- **J4** (in handset): the actual mating half for the handset cable, wired
  directly to SW3/SW4. Mates with a short pigtail off TB1/TB2.

## Screw terminals (board-side termination)

TB1, TB2, TB4, TB5 replace what used to be two board-side Mini-Fit Jr connectors
(J2, J1) - the board now only ever solders to a screw terminal (no crimp
tool needed for board assembly); a short crimped pigtail, off-board,
carries each circuit on from there to J3/J4's actual Mini-Fit pins. Real
part: Kicad's `Screw_Terminal_01x02`, 2-position, 2.54mm pitch.

- **TB4** (motor pair): 1=`MOT_A`, 2=`MOT_B` (also U4.1, U4.2 - IP+, both
  leads; K2.11 on pin 1). Circuit numbering here still matches what the
  former J2 used (README 1.6: motor pair = circuits 1/2). Which of
  MOT_A/MOT_B sits on pin 1 vs 2 is still provisional - MOT_A is defined
  by function (§1.6: whichever conductor raises the desk), not by a fixed
  pin, so if bring-up shows this backwards, relabel here rather than
  rewire.
- **TB5** (supply pair): 1=the unnamed VSW-potential net (see Power), 2=GND.
  Mirrored (pins face right, toward the SUPPLY chain) rather than left
  (toward TB4) - see `sch.py`.
- **TB1** (signal pair): 1=`HND_A` (also R3.2), 2=`HND_B` (also R4.2). No
  README-documented circuit numbering exists here (unlike TB4) - this
  assignment is for routing convenience only.
- **TB2** (power pair): 1=`+3V3`, 2=GND. Mirrored, same reasoning as TB5.

## Controller (U1 = ESP32)

Real part: Kicad's `ESP32-S3-DevKitC` (github.com/espressif/kicad-libraries,
CC-BY-SA 4.0 - vendored in `espressif.kicad_sym`, not part of the local Kicad
install). Bare devkit, no display - this hardware lives under the desk, not
somewhere a display is ever seen (README 5); a display, if ever added, would
be a separate on-desk peripheral. Chosen over `Arduino_Nano_ESP32` for its
bare GPIO-numbered pins, matching how this design already refers to every
signal (the Nano's exposed pins don't even overlap with the GPIOs this
design uses).

GPIO choice was picked for schematic-wiring simplicity, not final PCB
routing - expect this table to change once routing is considered. Only
constraints respected: avoid strapping (GPIO 0/3/45/46), avoid this specific
module's flash/PSRAM-reserved range (GPIO 22-37 - wider than the usual 26-32
since this is an N16R8/octal-PSRAM part), avoid native USB (GPIO 19/20), keep
ISENSE on an ADC1-capable pin (GPIO1-10; ADC2 and WiFi can coexist on the S3
unlike the classic ESP32, but ADC1 is still simpler).

| U1 pin | GPIO | Net | Goes to |
|---|---|---|---|
| 21 | (5V) | +5V | supply |
| 22 | (GND) | GND | ground (1 of 4 GND pins, only this one wired) |
| 1/2 | (3V3) | +3V3 | source for TB2/handset feed (2 physical pins, 1 wired, merged by Kicad's power matching) |
| 10 | GPIO17 | DIR_A | R8.1, U3.2 (gate A input) |
| 11 | GPIO18 | DIR_B | R9.1, U3.5 (gate B input) |
| 27 | GPIO21 | PWM | R10.1, U3.10 (gate C input) |
| 12 | GPIO8 | MODE | unconnected (spare) |
| 41 | GPIO1 | KICK | U2.1 (monostable A trigger input) |
| 40 | GPIO2 | ISENSE | R1.1, R2.2 (divider midpoint) |
| 18 | GPIO12 | - | unconnected (spare) - was SDA, moved off this pin, see below |
| 19 | GPIO13 | - | unconnected (spare) - was SCL, moved off this pin, see below |
| 35 | GPIO38 | SDA | TB3.1 (ToF prep, Phase 2 not started) - fully routed, see README 8.1 |
| 38 | GPIO41 | SCL | TB3.2 (ToF prep, Phase 2 not started) - fully routed, see README 8.1 |
| 15 | GPIO9 | SW_UP | R3.1, R5.2 |
| 16 | GPIO10 | SW_DN | R4.1, R6.2 |

DIR_A/PWM (GPIO17/21) aren't the classic-ESP32 assignment this design used to
use (GPIO21/27) - swapped so DIR_A, whose gate target is the topmost of the
three AND gates below, lands on the topmost of these three MCU pins, and PWM
(bottommost gate) lands on the bottommost; DIR_B (middle gate) was already in
between. The other ~30 pins on this real part (GPIO4-7, most of the JTAG/UART
pins, etc.) are unconnected - normal for a full-featured real MCU symbol
where a given design only uses a fraction of the breakout, not a sign of
anything missing. `CHIP_PU` (pin 3, the board's own EN) is also left
unconnected - it has an onboard pull-up on real devkits, no external drive
needed.

Rocker dividers: `HND_A` → R3 (4k7) → node also pulled to +3V3 through R5
(100k) → `SW_UP`. Same pattern for `HND_B`/R4/R6/`SW_DN`. Dry contacts, no
clamp diodes (29V can never reach these conductors).

## Watchdog + gating (U2 = 74HC123, U3 = 74HC08)

- U2 pin 1 (A, trigger) ← `KICK` (U1.41, GPIO1)
- U2 pin 2 (B) and pin 3 (Clr) both tied to +5V (never retriggers or clears
  from those inputs)
- U2 pins 14/15 (Cext/RCext) ↔ C1 (2u2) / R7 (100k) — sets the ~250ms pulse
  width
- U2 pin 13 (Q, watchdog output) → `WDOG` net → U3 pins 1, 4, 9 (the "A"
  input of each of the three AND gates)
- U2 pin 4 (~Q) — unconnected
- U2 pins 16/8 (VCC/GND) → +5V / GND

Each AND gate: `WDOG` AND `<signal>` → gated output to the corresponding FET.

| Gate | A (WDOG) | B (signal) | Y (out) | Pulldown | Drives |
|---|---|---|---|---|---|
| U3 unit 1 | pin 1 | pin 2 = DIR_A | pin 3 | R8 (10k) on pin 2 | Q3 gate |
| U3 unit 2 | pin 4 | pin 5 = DIR_B | pin 6 | R9 (10k) on pin 5 | Q4 gate |
| U3 unit 3 | pin 9 | pin 10 = PWM | pin 8 | R10 (10k) on pin 10 | R11 → Q1/Q2 base |

U3 pins 14/7 (VCC/GND, unit 5) → +5V / GND. Pulldowns hold each gated line
low (drive lines safe) before the MCU boots.

## Drive

- **Q1/Q2** (BC337/BC327, discrete push-pull gate driver - replaces a
  TC4427 driver IC, see README/APPENDIX for why): bases tied together ←
  U3 gate-3 output (pin 8) through R11 (1k); emitters tied together →
  **Q5.1** (gate). Q1 collector → +5V; Q2 collector → GND.
- **Q5** (IRLZ44N, main PWM FET): gate ← Q1/Q2 emitters; source → GND;
  drain (`MRET`) → K1.14, K2.14, D1.2.
- **D1** (SB560, freewheel): K → `MRET`; A → `VSW`.
- **Q3** (2N7000): gate ← U3 unit-1 output (pin 3); drain → K1's coil
  (`A1`/D2 node); source → GND.
- **Q4** (2N7000): gate ← U3 unit-2 output (pin 6); drain → K2's coil
  (`A1`/D3 node); source → GND.
- **K1** (relay, UP): coil A2 → +5V, coil A1 → Q3 drain + D2 cathode (D2
  anode → +5V, flyback) - A1/A2's roles swapped from a pre-rotation
  layout (`sch.py`'s own history); the schematic is correct, this doc
  wasn't. Contacts: 12 (NC) → `VSW`; 14 (NO) → `MRET`; 11 (COM) →
  `DRV_UP` net → U4 pin 3 (IP-).
- **K2** (relay, DOWN): same pattern - coil via Q4/D3; 12 (NC) → `VSW`; 14
  (NO) → `MRET`; 11 (COM) → TB4 pin 1 (`MOT_A`, pigtails on to the motor
  housing connector J3).
- **U4** (ACS712ELCTR-05B, current sensor): VCC (pin 8)/GND (pin 5) →
  +5V/GND. IP- (pin 3, both leads) ← K1.11 (`DRV_UP`). IP+ (pin 1, both
  leads) → TB4 pin 2 (`MOT_B`) — U4 sits in series in K1's leg only; K2's
  leg (`MOT_A`) bypasses it directly. Which of IP+/IP- faces which side
  is arbitrary (README 4.4 - either leg works, direction isn't used) and
  was picked for routing. VIOUT (pin 7) → R1.1. FILTER (pin 6) is
  unconnected - the datasheet ties it to GND through a cap for noise
  filtering; not fitted, open item.
- **R1/R2** (10k/20k): OUT → R1 → R2 → GND; the R1/R2 midpoint is `ISENSE`,
  fed to U1 pin 40 (GPIO2).

## Leg (unmodified motor housing internals)

- `MOT_A` → SW1.1 (top limit) ∥ D5.1 (bypass, "allows down") → common node
  (SW1.2, D5.2) → M1.1
- M1.2 → common node (SW2.1, D6.2) → SW2.1 (bottom limit) ∥ D6.2 (bypass,
  "allows up") → SW2.2/D6.1 → `MOT_B`

Note the diodes are reversed relative to each other pin-for-pin (D5: pin 1 on
the `MOT_A` side; D6: pin 1 on the `MOT_B` side) — that's the "allows
down"/"allows up" direction difference, not a mistake.

This section is physically inside the motor housing/leg and reached only via
J3 (which pigtails on to TB4/TB5 on the board) — it's the same hardware as
the stock desk, unmodified.

**Previously found here, since fixed:** `MOT_A`/`MOT_B` used to be global
labels placed only in this section, far from the board-side connector, which
meant they never actually merged with that connector's own pins in Kicad's
netlist (global labels merge by matching text anywhere on the sheet, and
those pins carried no such label). Fixed by adding `J3` — the actual mating
half, wired straight to this section's motor leads instead of relying on
label-matching. See `sch.py`.

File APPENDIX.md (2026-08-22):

# Appendix — background, rejected alternatives, future work

**Nothing in this file is required to build or maintain the current design.**
For that, read `README.md`.

This is where the rest of the design process lives: reasoning that is not yet
load-bearing, options that were evaluated and dropped, and analysis of work
that has not started. It exists so the next round begins where the last one
finished, rather than re-deriving the same conclusions.

Read it when you are about to propose an approach, change a parameter whose
value looks arbitrary, or start phase 2.

---

## 1. Control loop and sensing

### 1.1 Collision detection

**Use dI/dt against a rolling baseline, not an absolute threshold.** Baseline
current shifts with load, direction, temperature and position, so any fixed
trip point is either too twitchy when cold and loaded or too slow when warm
and empty.

**Downward travel is the hard case, and also the dangerous one.** Gravity is
assisting the motor, so an obstruction produces a *smaller* relative rise in
current than the same obstruction going up. The direction that most needs
detection is the one where the signal is weakest. Budget more sensitivity
going down, not less.

Note that the stock desk has no collision detection at all; the PSU current
limit is the only protection. Anything added here is a genuine improvement
rather than a restoration.

### 1.2 Reading current correctly under PWM

**Motor current and supply current differ by roughly the duty cycle.** During
a low-duty ramp the winding can carry two or three amps while the supply
contributes under one, the difference coming from the PSU's output
capacitance. Size the drive path on motor current; size the supply budget on
average current.

**The sensor must be in the motor leg, not the FET return.** With low-side
chopping the FET only conducts during the on-time — freewheel current bypasses
it entirely. A low-side shunt therefore reads a chopped fraction and needs
synchronous sampling inside the PWM on-window plus a duty correction. Placing
the ACS724 in the motor leg puts it inside the freewheel loop, so it reads
true motor current continuously. This is the main reason the Hall sensor won
over a shunt-plus-INA240, despite costing more.

### 1.3 Two free signals not currently used

**Rail sag as a load proxy.** Because the supply current-limits rather than
sagging gracefully, the 29 V rail collapses in a fairly binary way when demand
exceeds 1.8 A. A resistor divider on VSW into a spare ADC gives an obvious
"we are in current limit" flag — cheap redundancy alongside the shunt, and
useful for distinguishing a real obstruction from a sensor fault.

**Back-EMF during coast.** With the FET off and the relays released, the
voltage across the winding is proportional to speed. Useful for stall
detection and, more practically, for measuring coast distance after cutoff —
which is what sets preset accuracy.

### 1.4 Why 20 kHz PWM

Above audible, and comfortably short compared with the winding's electrical
time constant. With 2.5 Ω and a plausible 1–3 mH for a motor this size,
τ = L/R lands around 0.4–1.2 ms. At 20 kHz the period is 50 µs, well inside
that, so the current stays in continuous conduction and the motor sees an
effectively smooth average rather than a train of pulses.

### 1.5 Ramp tuning

Starting points are 500 ms up, 300 ms down, 50 ms settle. Tune by feel. Two
things to watch: a ramp that is too slow wastes time at low duty where torque
is marginal under load, and a ramp-down that is too fast reintroduces the
clunk you set out to remove.

Some of the perceived jolt on the stock desk was never electrical — spindle
backlash and the columns taking up load contribute, and no amount of ramping
removes that entirely.

### 1.6 Proposal: spare 74HC123 channel as a second, hardware-enforced timeout

**Not implemented — a design change, not a documentation fix. Needs
discussion before it goes into the schematic.**

U2 is dual (74HC123, §5.7) and only one channel is used, for the 250 ms
watchdog. The spare channel could provide a second, independent timeout: a
~30 s monostable retriggered by "any drive line active," hard-limiting how
long the desk can run continuously.

Why it would be worth doing: the travel timeout is currently a firmware
property (`max_run_ms`), so it dies with the firmware — a hung or buggy
control loop that keeps a drive line asserted has nothing hardware backing
it up past the existing (much shorter) watchdog. Moving the *duty-cycle*
limit into hardware makes maximum continuous run something the MCU cannot
override, the same way the existing 74HC123 channel already makes the
kick-or-stop behavior something the MCU cannot override. It would also
enforce the manual's duty-cycle limit (§1 of the manual, README §1.1)
against a firmware bug rather than only trusting firmware to enforce it.

What would need deciding before wiring it in: what "any drive line active"
should actually gate off if it trips (full stop, like the existing
watchdog, or just inhibit further starts until it resets?), and whether 30
s is the right figure against the manual's actual duty-cycle numbers.

---

## 2. Phase 2 — position sensing, full option analysis

### 2.1 What is actually required

**Repeatability matters more than absolute accuracy.** A consistent 4 mm
offset is invisible in use; 4 mm of jitter is not. Median-filter a handful of
samples and only trust a reading once motion has settled.

**Absolute encoding is not worth paying for.** The bottom limit switch is a
repeatable mechanical reference, detected by current collapse, so one trip
down re-homes the desk. That removes most of the appeal of absolute sensing
and opens up the cheap incremental options below.

### 2.2 Time-of-flight (leading candidate)

VL53L1X, mounted on the moving part and aimed **at the fixed foot plate**,
not at the floor. Same geometry, but the target is rigid and always present
rather than whatever ends up in the footwell.

- Range seen is roughly 600–1100 mm across the 68–118 cm travel. The top end
  is where the VL53L1X gets marginal: the ~4 m specification is a dark-room
  figure, and bright ambient IR pulls it toward ~1.3 m. **Prototype at maximum
  height before committing to a mount.**
- Long distance mode, timing budget 100–200 ms. At 25 mm/s that is only
  2–5 mm of travel per sample.
- Matte white target on the foot. Dark, glossy or textured surfaces cost
  signal exactly where margin is thinnest.
- Run offset and crosstalk calibration, especially behind any cover window.
- **If range proves marginal, measure one telescoping stage instead of the
  whole column.** On a 3-stage leg each stage moves about half the total, so
  the required range halves at the cost of needing the ratio.

### 2.3 Incremental optical or magnetic

- **Reflective sensor over a printed stripe.** 2 mm pitch printed on a laser
  printer, read with a QRE1113 or TCRT5000. Two sensors offset by a quarter
  pitch gives quadrature and direction. At 25 mm/s that is ~12 edges per
  second — trivially slow to process, and 1 mm resolution is far better than
  needed.
- **Magnetic strip and Hall sensor.** Same idea, immune to dust and grime,
  which matters under a desk. Alternating-pole tape plus an AS5311 is the
  clean version; a row of magnets and a Hall switch is the crude one.

The real cost of either is mechanical: a 500 mm scale mounted rigidly along
the travel, parallel and at controlled standoff, plus a head on the moving
part. Considerably fussier than pointing a sensor at a foot plate. What you
get back is resolution you do not need, plus immunity to the ambient-IR
problem that is ToF's main weakness here.

### 2.4 Commutator ripple counting

Zero additional hardware — it uses the current sensor already fitted. Ripple
for a motor like this lands somewhere in the few-hundred-hertz range, so it
needs a clean signal and a few kHz of sampling, not a module's coarse current
output.

Two catches: ripple gets messy under PWM, and counts are lost around start and
stop, which is precisely where accuracy matters. Workable as a cross-check
against another sensor, not as the primary.

**The ESP32-S3's continuous DMA ADC mode is what makes this realistic.** On a
classic ESP32 it is much harder. If there is an S3 in the parts box, prefer it
for that reason alone.

### 2.5 Membrane potentiometer

A 500 mm SoftPot spans the travel almost exactly and reads on one ADC pin.
Genuinely absolute, genuinely simple. Rejected because the wiper needs an
actuator and these wear — but worth remembering as the low-effort option if
the ToF mount proves awkward.

### 2.6 What will not work

**A 6/9-DOF IMU cannot give height.** It gives tilt and vibration; extracting
displacement means double-integrating acceleration, which drifts into
uselessness within seconds. A fine "the desk is moving" detector, a useless
position sensor.

---

## 3. Controller hardware options

### 3.1 CYD (ESP32-2432S028R)

The 2.8" ESP32-2432S028R is the well-documented variant. Free GPIO is
typically **IO21, IO22, IO27, IO35**, with IO16/IO17 available if two of the
RGB LED colours are given up. Most other pins go to display SPI, the separate
touch controller SPI, the SD slot, RGB LED, LDR and speaker.

That covers phase 1 exactly. Phase 2's I²C then costs the LED colours.
IO35 is input-only, which is fine for the ADC, and is on ADC1 — mandatory.

Caveats: newer USB-C revisions and the 3.5" boards shuffle connectors, so
check the specific board rather than a generic pinout guide. It is a bare
PCB, so an enclosure is still needed.

### 3.2 M5Dial

Considered first. The rotary knob suits height adjustment better than a touch
screen, and the price buys an enclosure and integration. Dropped on cost once
it became clear there were spare ESP boards and displays already to hand.

Its port allocation, if ever revisited: G1/G2 for the bridge inputs, G6 for
the watchdog kick, G7 for current sense (ADC1-capable), leaving Port A's I²C
free for the ToF.

### 3.3 Strapping pins

This bites specifically because the failsafe design *requires* external pull
resistors on the drive lines, which fight the bootloader if placed wrong. On
the classic ESP32 avoid GPIO0, 2, 12 and 15 — GPIO12 pulled high at boot sets
the wrong flash voltage. The S3's strapping set differs, but the principle
holds.

---

## 4. Firmware alternatives

### 4.1 Why not pure YAML

The three failures — watchdog kick timing, relay sequencing, and `adc` polling
being far too slow — are in **`README.md` §7**, because they justify a
structural choice someone might otherwise undo.

### 4.2 Arduino under PlatformIO

The pragmatic pure alternative: LEDC, a hardware timer for the tick,
ArduinoOTA. You lose Home Assistant integration unless you add MQTT yourself,
and the UI is hand-rolled. Reasonable if the goal is understanding every line.

### 4.3 Interim presets without position sensing

If presets start itching before phase 2 lands: home against the bottom limit
by watching for current collapse, then dead-reckon on run time. It drifts —
up and down speeds differ, and both vary with load — but re-homing costs one
trip to the bottom. The component already does this; `read_current_()` is what
makes the homing work.

---

## 5. Rejected approaches

Recorded so they are not re-proposed. Several were reasonable at the time and
became obsolete when a later measurement changed the picture.

### 5.1 Passive soft start

- **NTC inrush limiter in series with the motor.** Passive,
  polarity-agnostic, a twenty-minute experiment, and a good way to find out
  how much of the jolt is electrical versus mechanical. Its weakness is that
  it will not fully cool between short, frequent desk movements, so the effect
  fades with repeated use. Still arguably worth doing once as a diagnostic.
- **Series resistor shorted out by a relay after a delay.** A two-step ramp
  rather than a smooth one, but it removes the worst of the jolt for almost
  nothing.

### 5.2 Inline soft starter, controller left intact

Before it was established that no controller exists, the plan was to insert a
soft starter between the control box and the motor without touching either.

Because the box reverses polarity, the device had to be polarity-agnostic: a
bridge rectifier with the motor in series on the AC side and a MOSFET across
the DC rail. It can self-power from the rectified rail, since full supply
voltage sits across it while the FET is off. The minimal version ramps the
gate with an RC network, running the FET in linear mode — needs a heatsink and
a bleed resistor, but no microcontroller.

Two problems killed it. Chopping an inductive load needs a freewheel path, and
a plain antiparallel diode will not do when polarity reverses — you need a
second bridge across the motor with its DC terminals joined through a diode.
And once it became clear the rockers *were* the H-bridge, replacing them was
strictly simpler than wrapping them.

### 5.3 Keeping the OEM handset in the circuit

- **PhotoMOS or optocoupler taps across the rocker contacts** (AQY212 and
  similar). This works only if the rockers switch *signals*. They switch full
  motor current, so it was never applicable — but it was the plan for several
  messages before that was measured.
- **Leaving the rockers wired in parallel as a fallback.** Actively
  dangerous with any electronic drive: the rockers would short the drive
  outputs directly to the supply rails. Either remove them from the motor
  circuit entirely, or use a changeover with no position where both are live.
- **Optocoupler rocker sensing** (PC817 across each handset conductor,
  ~6 mA through a 4k7 half-watt resistor). Correct, isolated, and superseded
  once the board began feeding the handset 3.3 V, which makes the rockers dry
  contacts readable straight into GPIOs.

### 5.4 H-bridge ICs

Rejected on voltage headroom rather than current — see README §6.1. If ever
revisited, the parts with genuine headroom at 29 V are the Pololu G2 24v13
(rated to 40 V, current sense output, sleep pin ideal for the watchdog) and
the DRV8876 (4.5–37 V, ~3.5 A, IPROPI current mirror, nSLEEP).

Also worth remembering: an integrated bridge deletes the FET, the gate driver
and the freewheel diode, so the part count difference is smaller than it
looks. What it costs you is the shoot-through failure mode that relays simply
do not have.

### 5.5 Single DPDT relay for direction

Cheaper than two SPDTs and adequate for direction, but **it has no neutral
state**. Wired the standard reversing way, de-energised gives one direction
and energised the other; there is no third position, so it cannot brake. This
is exactly why the OEM used two independent changeovers.

### 5.6 Transfer relay with automatic fallback

Kept as a schematic (`desk_inline.*`, since dropped — see §7) for a long time
because it is a good design, not a bad one. Three extra relay poles buy
in-place OEM fallback: power loss or a watchdog timeout hands the desk back
to the rockers with no intervention. Dropped only because reverting by
unplugging the box was judged good enough.

If it is ever revived, the one subtlety worth keeping is that the transfer
poles carry full motor current in OEM mode and must be rated accordingly,
while a watchdog trip is self-safe because the FET turns off in microseconds
and the relays take milliseconds to release.

### 5.7 74HC122 for the watchdog, instead of 74HC123

Functionally the better fit: a single-channel retriggerable monostable with
overriding clear, and its internal 10k timing resistor would eliminate R7,
leaving only C1. Considered as a replacement for the dual 74HC123 U2 uses
(only one of its two channels is populated).

**Discontinued in the HC family.** Searches for an HC122 datasheet return the
HC123 instead, and no current NXP or TI HC122 part page exists. The '122
survives as 74LS122 only, and dragging a TTL part into an otherwise HC design
buys nothing. Retaining 74HC123, recorded here so the question is not
reopened and re-researched later.

**CD4538** (dual precision retriggerable monostable) is worth noting as the
alternative if timing tolerance ever matters — the HC123's timing spread is
famously loose. It does not matter for a 250 ms watchdog, which only needs to
sit comfortably above the 50 ms kick interval and below "dangerous".

**74x121 and 74x221 will not work** for this — both are non-retriggerable
one-shots, and the watchdog's whole point is retriggering on every kick.

---

## 6. Evidence worth capturing

While the desk is apart, and not obtainable later:

- Photographs of the handset internals, the motor housing terminals, and the
  connector halves next to a ruler.
- Any label on the motor housing. A model string would be the single highest-
  value data point — OEM parts usually carry one, and if it maps to a Jiecang
  / Kaidi / TiMOTION part, a real datasheet suddenly exists.
- Current traces for a full travel in each direction, and coast distance after
  cutoff at a few speeds. This is exactly the calibration data phase 2 needs,
  and it comes free from normal use once the board is in.
- If commutator ripple turns out to be cleanly visible on those traces, the
  cheapest position sensor may be the one already built.

Contacting 2-connect for a spare control box also costs nothing. Even a
refusal often arrives with a model number attached.

---

## 7. Tooling notes

**Schematics are generated.** `schlib.py` provides symbol definitions with
absolute pin lookup, orthogonal wire routing and junctions; `sch.py` lays
out the sheet. Edit the generator, never the `.kicad_sch`. Generator and
dependencies live in `schematics/gen/`; the `.kicad_sch`/`.pdf`/`.svg` and
`NETLIST.md` land one level up in `schematics/` — machine-facing tooling
kept apart from the human-facing result.

**Format version is KiCad 7 (`20230121`)**, chosen because that is what
`kicad-cli` was available at. KiCad 7, 8 and 9 all open it. Symbols are
embedded verbatim (hand-drawn, or copied out of real KiCad libraries via
`import_symbol()`), so there are no external library dependencies at
open-time.

Export (from `schematics/gen/`):

```sh
kicad-cli sch export pdf -o ../desk.pdf ../desk.kicad_sch
cd .. && kicad-cli sch export svg desk.kicad_sch   # -o always names a
                                                    # directory for svg,
                                                    # never a file - cd
                                                    # first instead
```

**Two dead ends in the drawing work**, recorded so they are not repeated:

- Rendering the netlist as a graphviz connectivity graph is a useful *audit*
  tool — it caught a real wiring error where a schematic note and the netlist
  disagreed — but it is not a schematic and should not be presented as one.
- Running literal power rails across the sheet, in an attempt to remove
  visually disconnected "islands", made things worse: every ground became a
  long vertical and the sheet turned into a picket fence. Local GND and rail
  symbols are the conventional idiom precisely because they avoid this. The
  actual problem in that draft was that *signals* were labelled rather than
  wired.

**ERC has been run** (`kicad-cli sch erc`): 127 violations, all triaged as
documented gaps or power-flag/embedded-symbol artefacts — no structural
defects. See README §9.

**`sch_simple.py` was not actually regenerable when this repo was first
committed.** It pulled its symbol library in with
`exec(open("/home/claude/kicad/_sym_preamble.py").read())` — a file that only
ever existed in the sandbox the original Claude.ai session ran in, and was
never part of the export. `sch_original.py` and `sch_inline.py` had already
been migrated to a normal `from schlib import ...` and defined their symbols
inline, so only `sch_simple.py` was affected, but it's the chosen design —
the committed `desk_simple.kicad_sch` was an artefact nothing in the repo
could reproduce. All three generators also wrote their output to that same
sandbox path (`/home/claude/kicad/desk_*.kicad_sch`) instead of the working
directory.

Fixed by extracting the symbol set `sch_simple.py` needs into `symbols.py`
(copied from the equivalent block already inline in `sch_inline.py` — the two
generators need the same symbols) and pointing the relevant `open()` calls at
the local directory. Verified by regenerating all three `.kicad_sch` files
and diffing byte-for-byte against what was already committed: identical.
`sch_inline.py` was left with its own inline copy rather than switched to
import `symbols.py` too, since it already worked and didn't need touching.

A `Makefile` in `schematics/gen/` now runs the full `.py → .kicad_sch →
.pdf/.svg` chain. It marks the `.kicad_sch` target `.PRECIOUS` — without
that, GNU Make treats a file that is a build product of one rule and only a
prerequisite of another as a disposable intermediate and deletes it after
use, which would silently delete the tracked schematic.

**`make check`** (same Makefile) runs `find_shorts.py`/`find_diagonals.py`/
`find_crossings.py`/`find_body_crossings.py` — schematic-quality checkers
that trace `sch.py`'s actual `wire()`/`place()` calls (via `_trace.py`,
which monkeypatches both before importing `sch`) rather than re-parsing the
`.kicad_sch` output, so they see exactly what the generator draws. Previously
these were recreated from scratch each session (lost across context
compactions); persisted here instead. One bug found while persisting them:
the tracer recorded wire() calls' raw pre-snap arguments instead of the
post-`_snap_pt()` coordinates actually drawn, producing false-positive
"diagonal" reports for wires that render perfectly orthogonal - fixed by
snapping inside the tracer the same way `wire()` does internally.

**`sch_original.py`/`sch_inline.py` and their outputs were dropped once the
symbol migration and layout cleanup on the chosen design were done.**
`desk_original` was the stock desk's own wiring — fully described by §1/§2's
measurements, so keeping a duplicate schematic added nothing. `desk_inline`
was design 3.3 (README §3), a good design but over-complex, kept only for
reference while 3.4 was still being finished; once 3.4 (this file) was
settled, keeping a second maintained generator around had no further purpose.
With only one sheet left, `sch_simple.py`/`desk_simple.*` were renamed to
`sch.py`/`desk.*` — "simple" was only ever a name to distinguish it from the
other two.

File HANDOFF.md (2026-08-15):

# Handoff — changes to apply to `desk-retrofit`

These came out of a claude.ai session working alongside you. Apply them on top
of whatever is currently in the repo; rebase rather than assuming the tree
matches what that session last saw.

Ground rules that already exist in `CLAUDE.md`, repeated because they matter
for every item below:

- **Never edit `.kicad_sch` directly.** Edit `schematics/sch_*.py` and
  regenerate.
- **Run `cd schematics && make sch && make verify` after any schematic
  change.** UUID generation is deterministic, so `verify` is an exact drift
  check and must report OK for all three sheets before committing.
- Record *why*, not just what. `README.md` §5 is the corrections list; add to
  it when a decision reverses.

---

## 1. Replace 2N7002 with 2N7000 (through-hole)

**Files:** `schematics/sch_simple.py`, `schematics/sch_inline.py`,
`README.md` BOM.

`Q2`/`Q3` (relay coil drivers) are specified as **2N7002**, which is SOT-23
only. This project is deliberately all through-hole for protoboard assembly.

Replace with **2N7000** (or BS170) in TO-92: logic-level gate, 60 V, 200 mA
continuous, comfortable against ~70 mA relay coils. Drop-in, no other changes.

---

## 2. Record the 74HC122 investigation as a negative result

**File:** `APPENDIX.md` §5 (rejected alternatives).

The single-channel 74x122 was considered as a replacement for the dual
74HC123 in the watchdog. It is functionally the better fit — single
retriggerable monostable with overriding clear, and its **internal 10k timing
resistor would eliminate R3**, leaving only C3.

**It is discontinued in the HC family.** Verified: searches for an HC122
datasheet return the HC123 instead, and no current NXP or TI HC122 part page
exists. The '122 survives as 74LS122 only, and dragging a TTL part into an
otherwise HC design buys nothing.

**Decision: retain 74HC123.** Record this so the question is not reopened and
re-researched later.

Also note **CD4538** (dual precision retriggerable monostable) as the
alternative if timing tolerance ever matters — the HC123's timing spread is
famously loose. It does not matter for a 250 ms watchdog, which only needs to
sit comfortably above the 50 ms kick interval and below "dangerous".

And note that **74x121 and 74x221 will not work** — they are non-retriggerable
one-shots.

---

## 3. Propose a use for the spare half of the 74HC123

**File:** `APPENDIX.md` (future work). **Do not wire this into the schematic
without discussion** — it is a design change, not a documentation fix.

The 74HC123 is dual and only one channel is used. The spare could provide a
**second, independent hardware timeout**: a ~30 s monostable retriggered by
"any drive line active", hard-limiting continuous run.

Why it is attractive: the travel timeout is currently a firmware property
(`max_run_ms`), so it dies with the firmware. Moving it into hardware makes
maximum continuous run a property the MCU cannot override, complementing the
existing watchdog. It also enforces the manual's duty-cycle limit against a
firmware bug rather than trusting firmware to enforce it.

---

## 4. Note the through-hole constraint in the BOM

**File:** `README.md` §6.

Add that the design is **deliberately all through-hole** for protoboard
assembly, and list the packages so substitutions preserve it:

| Part | Through-hole option |
|---|---|
| 74HC123 | `74HC123N` / `SN74HC123N`, DIP-16 |
| 74HC08 | `SN74HC08N`, DIP-14 |
| TC4427 | `TC4427CPA`, DIP-8 |
| IRLZ44N | TO-220 |
| 2N7000 | TO-92 |
| SB560 | DO-201AD axial |
| TVS 33 V | `P6KE33CA` or `1.5KE33CA`, axial |
| Coil flyback | `1N4148`, DO-35 |
| ACS724 | Pololu carrier (0.1" holes) — the bare chip is SOIC-8 |
| Buck / ESP32 / relays | modules with headers |

The ACS724 is the one part where the carrier, rather than the chip, is what
keeps the board through-hole. Note that trade-off explicitly.

---

## 5. Record sourcing constraints (Netherlands)

**File:** `README.md` §6, near the existing sourcing paragraph.

Ruled out, with reasons, so they are not re-evaluated:

- **Digikey** — ~€25 shipping on small orders.
- **Farnell** — €50 order minimum, even after a reduction.

Working pattern is **two orders**:

- **Jellybean components** — Reichelt (DE) or TME (PL). Both ship to NL for
  single-digit shipping with no minimum. TME has the deeper catalogue.
- **Modules** — TinyTronics (Ede), Kiwi Electronics, Opencircuit (Zaandam) or
  Antratek. Kiwi and Antratek carry Pololu, which matters for the ACS724
  carrier.

**Mouser is being evaluated** as a possible single-order option — its European
free-shipping threshold may be low enough to cover the whole BOM including the
bare ACS724. Leave this marked as open; do not write it up as decided.

Substitutes worth recording:

- **TC4427** → TC4420, MCP1407, UCC27517, or a discrete totem-pole. Any driver
  sourcing a few hundred mA works; the arithmetic is in `APPENDIX.md` §1.5.
- **IRLZ44N** → any 55–60 V logic-level N-channel in TO-220. Check **Qg and
  VDSS**, not Vgs(th).
- **74HC08** → 74HC00 with inverted logic, or 74HC11 triple 3-input AND.
- **ACS724 carrier** → 10 mΩ shunt + INA240, but INA240 is SOIC-8 and needs a
  breakout, which fights the through-hole preference.

---

## 6. Pin down the current sensor specification

**File:** `README.md` §6, and `APPENDIX.md` §1.2 if useful.

"ACS724" alone is **not a specification** — prices vary ~5x because the name
spans a bare SOIC-8 chip, a carrier board, five current ranges, and
unidirectional vs bidirectional variants. Buying the wrong one degrades
collision detection quietly rather than visibly.

Two requirements:

- **Bidirectional (`AB` suffix).** Current reverses when the relays flip. A
  unidirectional `AU` part reads zero for one direction of travel.
- **5 A range**, not 20 A or 30 A. Sensitivity scales inversely and the
  working span is 0–3 A.

| Part | Sensitivity | Swing over 0–3 A |
|---|---|---|
| ACS724-5AB | 400 mV/A | 1.2 V |
| ACS712-05B | 185 mV/A | 0.55 V |
| ACS712-20A | 100 mV/A | 0.30 V |
| ACS712-30A | 66 mV/A | 0.20 V |

Cheap €2 modules are nearly always 20 A or 30 A. At 66 mV/A an obstruction has
to be detected inside 200 mV of a noisy ADC range.

Options: Pololu ACS724 5 A bidirectional carrier (€10–15); bare
`ACS724LLCTR-05AB-T` on a SOIC-8 breakout (~€5, 1.27 mm pitch is hand-solderable);
or an **ACS712-05B** module (€2–4) as a budget fallback — older and noisier,
but adequate with averaging in a 200 Hz loop, *provided it is the 5 A version*.

Warn about clone modules labelled ACS724 that are actually ACS712, and about
automotive `KMA` variants that cost more for no benefit here.

---

## 7. Confirm two earlier fixes are present

Both were made in the claude.ai session; verify they survived into the repo
rather than assuming.

- **`Q1` must be `IRLZ44N` (55 V), not `IRLB8721`.** The IRLB8721 is a 30 V
  part on a 29 V nominal / 30 V unloaded rail; at PWM turn-off the freewheel
  diode clamps the drain to VSW plus a diode drop, putting it at or over its
  absolute maximum every cycle. `README.md` §6.2 should lead with the voltage
  rating and give the substitution criterion as Qg and VDSS.
- **`schematics/symbols.py` exists and no generator uses `exec()`.** All three
  generators should resolve paths from `__file__`, and `make verify` should
  pass.

---

## Not yet decided — do not write these up as settled

- Mouser single-order viability (item 5).
- Final current sensor choice between the Pololu carrier, a bare chip on a
  breakout, and an ACS712-05B module (item 6).
- Whether to actually implement the second hardware timeout (item 3).

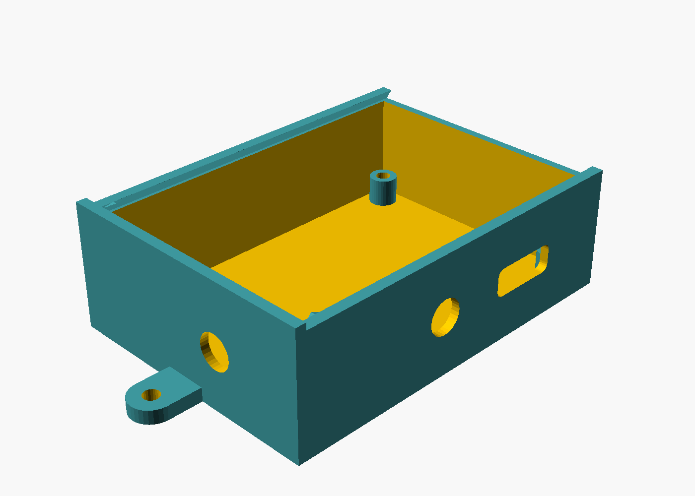
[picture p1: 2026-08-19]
enclosure/render_exterior.png

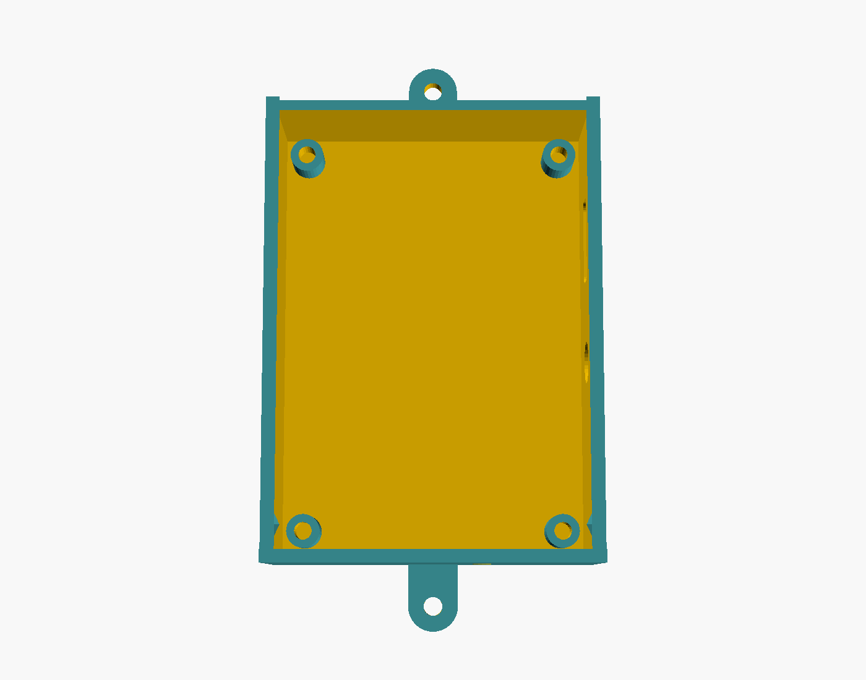
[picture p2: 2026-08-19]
enclosure/render_floorplan.png

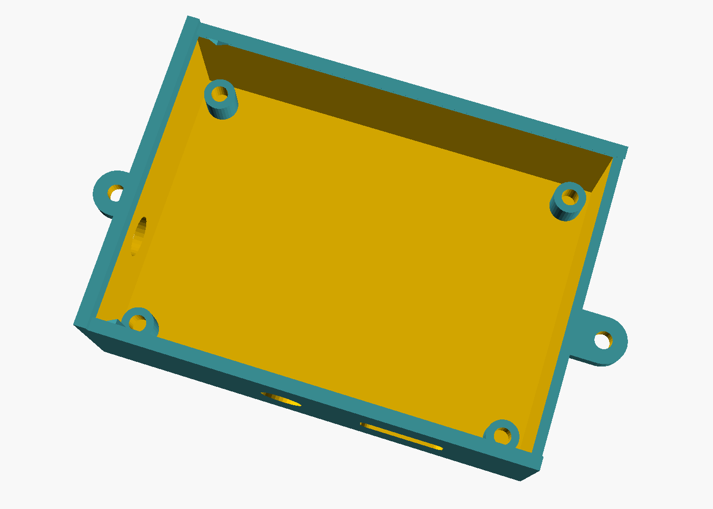
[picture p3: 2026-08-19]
enclosure/render_interior.png

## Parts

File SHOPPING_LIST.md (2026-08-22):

# Shopping list

Purchase-ready BOM. Check off as ordered — don't delete rows.

## Resistors (THT, 1/4W unless noted)

- [x] 10k — qty 4 (R8, R9, R1, R10)
- [x] 20k — qty 1 (R2)
- [x] 100k — qty 3 (R7, R5, R6)
- [x] 4k7 — qty 2 (R3, R4)
- [x] 1k — qty 1 (R11)

## Capacitors (THT)

- [x] 220µF, ≥50V — qty 1 (C4)
- [x] 220µF, ≥10V — qty 1 (C5)
- [x] 2.2µF — qty 1 (C1)
- [x] 100nF (0.1µF), ≥10V — qty 1 (C2)
- [x] 1nF — qty 1 (C3)

## Diodes

- [x] 1N4148, DO-35 — qty 2 (D2, D3)
- [ ] SB560, DO-201AD axial — qty 1 (D1), order 5
- [ ] TVS, 33V bidirectional (`P6KE33CA` or `1.5KE33CA`, axial) — qty 1 (D4), order 5

## Current sensor

- [ ] ACS712ELCTR-05B, SOIC-8 — qty 1 (U4), order 3
- [ ] DIP-8 IC socket, 0.3"/7.62mm — qty 1, order 5

## Transistors

- [ ] 2N7000, TO-92 — qty 2 (Q3, Q4), order 10
- [x] BC337, TO-92 — qty 1 (Q1)
- [x] BC327, TO-92 — qty 1 (Q2)
- [ ] IRLZ44N, TO-220 — qty 1 (Q5), order 3. **Not IRLB8721** (30V VDSS too low for this rail).

## ICs (THT/DIP)

- [ ] 74HC123N / SN74HC123N, DIP-16 — qty 1 (U2), order 3. **Must be retriggerable** — not 74HC221.
- [ ] DIP-16 IC socket, 0.3"/7.62mm — qty 1, order 5
- [ ] SN74HC08N, DIP-14 — qty 1 (U3), order 3
- [ ] DIP-14 IC socket, 0.3"/7.62mm — qty 1, order 5

## Buck regulator

- [ ] LM2576HVS-5.0/NOPB, TO-263-5 SMD — qty 1 (U5), order 2. Must be the true **HV** variant.

## Relays

- [ ] Omron `G5LE-1-5VDC`, SPDT/Form-C, 5V coil, 10A/250VAC-30VDC — qty 2 (K1, K2), order 4

## Board-side terminals

- [x] 2-position screw terminal, 2.54mm pitch — qty 5 (TB1-TB5), order 8. Degson `DG308-2.54-02P-14-00A(H)`.

## Modules

- [x] ESP32-S3-DevKitC — qty 1 (U1). Row spacing 25.4mm (1") — verify against the unit received.
- [x] 2× 2.54mm-pitch female header, 1×22 position (sockets U1) — covered by inventory.

## Connectors (Molex Mini-Fit Jr., 4-circuit)

- [x] Receptacle housing, 4-circuit — Molex `39-01-2040` — qty 2
- [x] Plug housing, 4-circuit — Molex 5559-04P — qty 2
- [x] Female crimp terminal, 5556 series — qty 8
- [x] Male crimp terminal, 5558 series — qty 8

Also needed: crimp tool, wire for the two pigtails + coupler (20-22 AWG).

## PCB / CNC

- [ ] 150×100mm copper-clad blank, double-sided, 1.5mm — pack of 5 (sourcing map, Amazon.nl `B07RFRVTGB`)
- [ ] CNC V-bit, 1/8" shank, 15° — Genmitsu `70V15` (Amazon.nl `B07P99C2FH`)
- [ ] Flat-nose end mill, 1/8" shank — Genmitsu `FN10A`-family (Amazon.nl `B07P7LGQJ6`)
- [ ] DIP IC socket assortment, 66pcs, 6-28 pin — Amazon.nl `B0C442NFWC` (covers the DIP-8/14/16 sockets above)
- [ ] M3 hardware for corner mounting holes (H1-H4, 3.2mm NPTH) — hold off until enclosure is finalized

## Not purchased (already exists / out of scope)

- PS1, M1, SW1/SW2, D5/D6 — inside the existing motor housing/leg
- Phase 2 parts (VL53L1X carrier + bracket) — not started

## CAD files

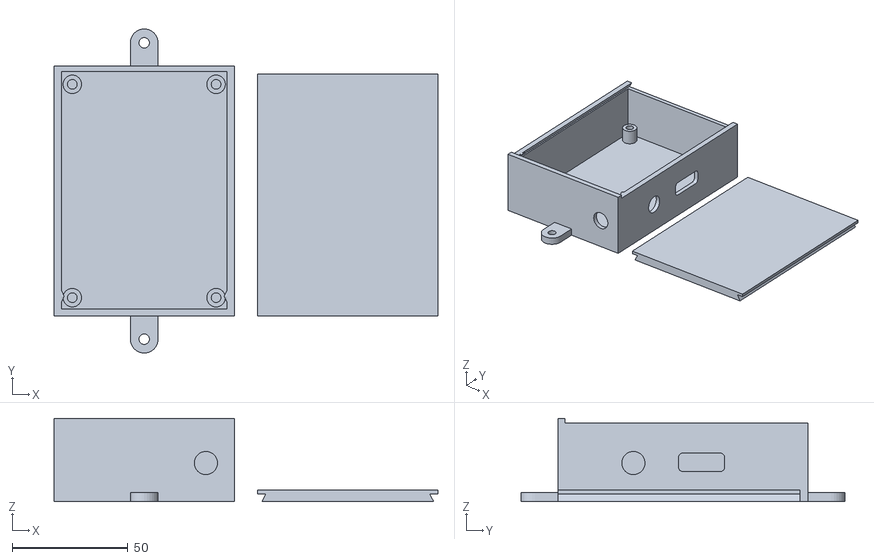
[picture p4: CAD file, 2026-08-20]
enclosure/shell.stl
165.6 x 139.8 x 36.0

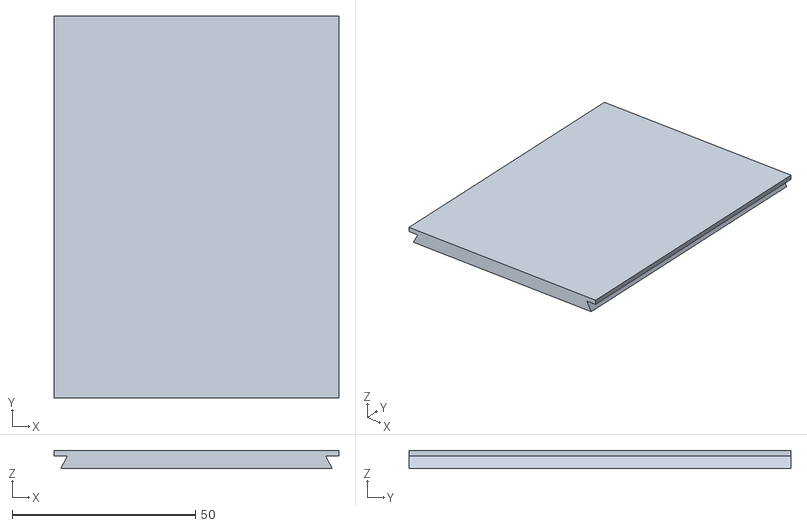
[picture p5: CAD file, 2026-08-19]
enclosure/cover.stl
77.8 x 104.3 x 5.00

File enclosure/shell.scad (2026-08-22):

// Single-shell enclosure for desk.kicad_pcb (70x100mm, 2-layer).
//
// The floor is solid and is what mounts to the desk (mounting ears flush
// with it, screwed straight into the desk). Standoffs rise from the floor
// to the PCB's back (solder) side, so the component side faces the open
// top - screws for the PCB go in from that same accessible top, down into
// heat-set inserts in the standoffs.
//
// The top is closed by a flat cover that slides on over the top of the
// shell on a dovetail joint - a wedge-shaped rail on each long wall's top
// edge, tapered only on its inner face (narrow where it meets the wall,
// gradually widening toward the interior as it rises), mating with a
// matching groove cut into the cover. Earlier attempts: a snap-fit lid
// (dropped - too brittle/fiddly for FDM); a fully-captured internal
// channel (dropped - its retaining lip needed an unsupported horizontal
// overhang the full length of the wall to print); an open-top groove
// with ribs (dropped once it was clear this mounts hanging under a desk -
// the cover's own weight would pull it straight out through the open
// top, since nothing was actually capturing it against gravity); a
// dovetail tapered on both faces (dropped - symmetric widening meant it
// overhung past the wall's own outer face on one side and further into
// the interior than needed on the other; only one sloped face is needed
// for the interlock). The remaining taper is shallow enough (~34° off
// vertical) to be self-supporting - each layer only slightly wider than
// the one below, not a true overhang - so the wall side prints with no
// bridging at all; the matching groove lives entirely in the cover, which
// prints lying flat, so its shape costs nothing there either. The front
// wall is left solid to stop the cover when closed; the rail ends flush
// with the back wall, which doubles as the open-end stop - the cover
// comes free by tilting it up once slid back far enough to mostly clear
// the taper. This is a first-draft mechanism: the
// dovetail/clearance dimensions below are estimates, not measurements,
// and want a test print before being trusted.
//
// All PCB-derived dimensions are measured directly from desk.kicad_pcb via
// the pcbnew Python API, not eyeballed from the PDF/SVG render - see the
// session history for exactly how (courtyard-bbox queries per footprint).
// Re-measure and update these if the board is ever revised.

// ---- PCB ----
pcb_w = 70;
pcb_h = 100;
pcb_t = 1.6;              // standard FR4 thickness

// H1-H4: 3.2mm NPTH, 4mm inset from each corner (commit 62d88ca)
hole_inset = 4;
hole_d = 3.2;

// ---- Component clearance ----
// Tallest parts are all THT and none have a confirmed datasheet height in
// this project's docs - this is an estimate, not a measurement:
//   - K1/K2 (SRD-05VDC-SL-C relay): ~16mm typical for this package
//   - U1 (ESP32-S3-DevKitC): pin socket (~8.5mm) + devkit PCB (~1.6mm) +
//     tallest part on the devkit itself (module/connector, ~3.5mm) = ~14mm
//   - Q5 (TO-220, upright): ~10-14mm depending on lead bend. U5 was this
//     too, but is SMD now (TO-263-5, laid flat - see conversation) and
//     no longer belongs in this list; well under any of the others.
//   - C4/C5 (220uF radial electrolytic): commonly 12.5-16mm tall
// Using 16mm + 3mm safety margin. Cheap to revise once real parts are in
// hand (see SHOPPING_LIST.md) - this is the single number to change.
component_clearance = 19;

// ---- Shell geometry ----
wall_t = 2.4;              // FDM-friendly - 2 perimeters at a common 0.4mm/1.2mm nozzle
floor_t = 2.4;             // solid floor slab - the face that mounts to the desk
xy_clearance = 1.5;        // gap between PCB edge and inner wall, all sides
                            // (U1's courtyard, USB-C overhang included, stays
                            // within PCB x:3.2-69.1 - checked directly via
                            // the pcbnew Python API - so it never reaches
                            // either board edge and needs no extra allowance
                            // here; see the USB slot's own comment in
                            // shell() for which wall it actually overhangs
                            // toward)

// standoff: cylindrical post rising from the floor to the PCB's back
// surface, with a pilot hole for an M3 heat-set insert (common brass
// insert OD ~4.0-4.2mm; using 4.2mm for an easy press-fit) opening from
// the TOP of the post (the PCB-facing end, now the accessible side) - the
// screw drives down from above, through the PCB, into it. Tall enough for
// the 6mm-deep insert plus a 2mm floor of material below it.
standoff_od = 8;
insert_hole_d = 4.2;
insert_depth = 6;
standoff_h = insert_depth + 2;
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

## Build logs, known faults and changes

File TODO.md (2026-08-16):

# TODO

Working list of what's outstanding. Not a durable doc like `README.md` /
`APPENDIX.md` — check items off once done or superseded, don't delete them.

## Schematic layout (schematics/sch.py)

- [x] **Snap all coordinates to KiCad's grid.** Done in `schlib.py`
  (`GRID`/`_snap`/`_snap_pt`, applied in `wire`, `place`, `pin`, `junction`).
- [x] **J2 (motor housing connector) placement/routing.** Settled — see
  `sch.py`.
- [x] **Rocker divider cluster (R11/R13/R14/R15) + J3 (handset connector).**
  Settled — see `sch.py`.
- [x] Re-run the full detector suite (diagonals / shorts / crossings /
  body-crossings). Now persisted as `schematics/gen/find_*.py`, run via
  `make check`. Found one bug in the checker itself (diagonals false
  positives from checking pre-snap coordinates), fixed; the 15
  crossings/6 body-crossings that remain are legitimate unconnected
  crossings and cosmetic-only body proximity, not defects.
- [x] Full visual re-render/review of `desk`. Done (task #11).

## Deferred ideas

- [x] Consider replacing hand-drawn symbols (`schlib.py`/`symbols.py`) with
  real local KiCad libraries where cleaner ones exist. Done — tasks #1-10
  migrated relays, logic ICs, MCU, connectors, passives and power flags to
  real KiCad library parts.

## From HANDOFF.md — not yet applied

Came out of a separate claude.ai session; ground rules and full detail are in
that file. Titles only, for a quick glance:

- [x] 1. Replace 2N7002 with 2N7000 (through-hole). Done — `sch.py` Q2/Q3
  now `2N7000`; added the missing BOM row (README §6).
- [x] 2. Record the 74HC122 investigation as a negative result. Done —
  `APPENDIX.md` §5.7.
- [x] 3. Propose a use for the spare half of the 74HC123. Written up as a
  proposal (not implemented, per HANDOFF's own instruction) in
  `APPENDIX.md` §1.6: a second, hardware-enforced ~30s continuous-run
  timeout.
- [x] 4. Note the through-hole constraint in the BOM. Done — `README.md`
  §6.5, adapted for parts that changed since HANDOFF was written (TC4427
  dropped, replaced by the already-through-hole discrete BC337/BC327).
- [x] 5. Record sourcing constraints (Netherlands). Done — `README.md`
  §6.6 (Digikey/Farnell ruled out with reasons, two-order pattern,
  Mouser left open, substitutes list). TC4427 substitute dropped, not
  applicable since the driver is discrete BC337/BC327 now.
- [x] 6. Pin down the current sensor specification. Already decided in the
  schematic, just not narrated where HANDOFF looked: `symbols.py` imports
  `ACS724xLCTR-05AB` for U5 (bidirectional, 5A range — exactly HANDOFF's
  two requirements), and README §4.4 already assumes this part. HANDOFF's
  "Not yet decided" framing was stale relative to the repo.
- [x] 7. Confirm two earlier fixes are present. Half held, half didn't:
  `symbols.py` exists and no generator uses `exec()` — confirmed OK. Q1
  was still `IRLB8721` (30V) on the 29-30V rail, not `IRLZ44N` (55V) as
  the earlier session intended — genuinely hadn't survived into the repo.
  Fixed now (`sch.py`, README §6.2/§5 item 9).
- [ ] (see "Not yet decided" section at the end of HANDOFF.md too — stale
  on item 6, see above; items 3 and 5's Mouser question still genuinely open)

## Known gaps (already tracked in CLAUDE.md "Open work")

- [x] ERC has never been run on any schematic. Run this session (task #11):
  127 violations, all triaged as documented gaps or convention artefacts.
- [x] Relay module active-high vs active-low polarity is unverified.
  Moot - K1/K2 are bare relays with their coils driven directly by
  Q2/Q3/D2/D6 (see NETLIST.md Drive section, README §6.3), not a
  driver-included module with its own logic-level input. Boot-safe
  behavior is by construction: R1/R2/R6 hold the AND-gate outputs low
  at boot, which holds Q2/Q3 (logic-level N-channel) off, which holds
  both coils de-energized - matching CLAUDE.md's "both relays off =
  brake" boot-state invariant with nothing left to verify against an
  external module's polarity.
- [ ] `read_current_()` in `desk_cover.cpp` is a stub (IDF 4.x vs 5.x ADC call).
- [ ] Phase 2 (position feedback, presets) not started.

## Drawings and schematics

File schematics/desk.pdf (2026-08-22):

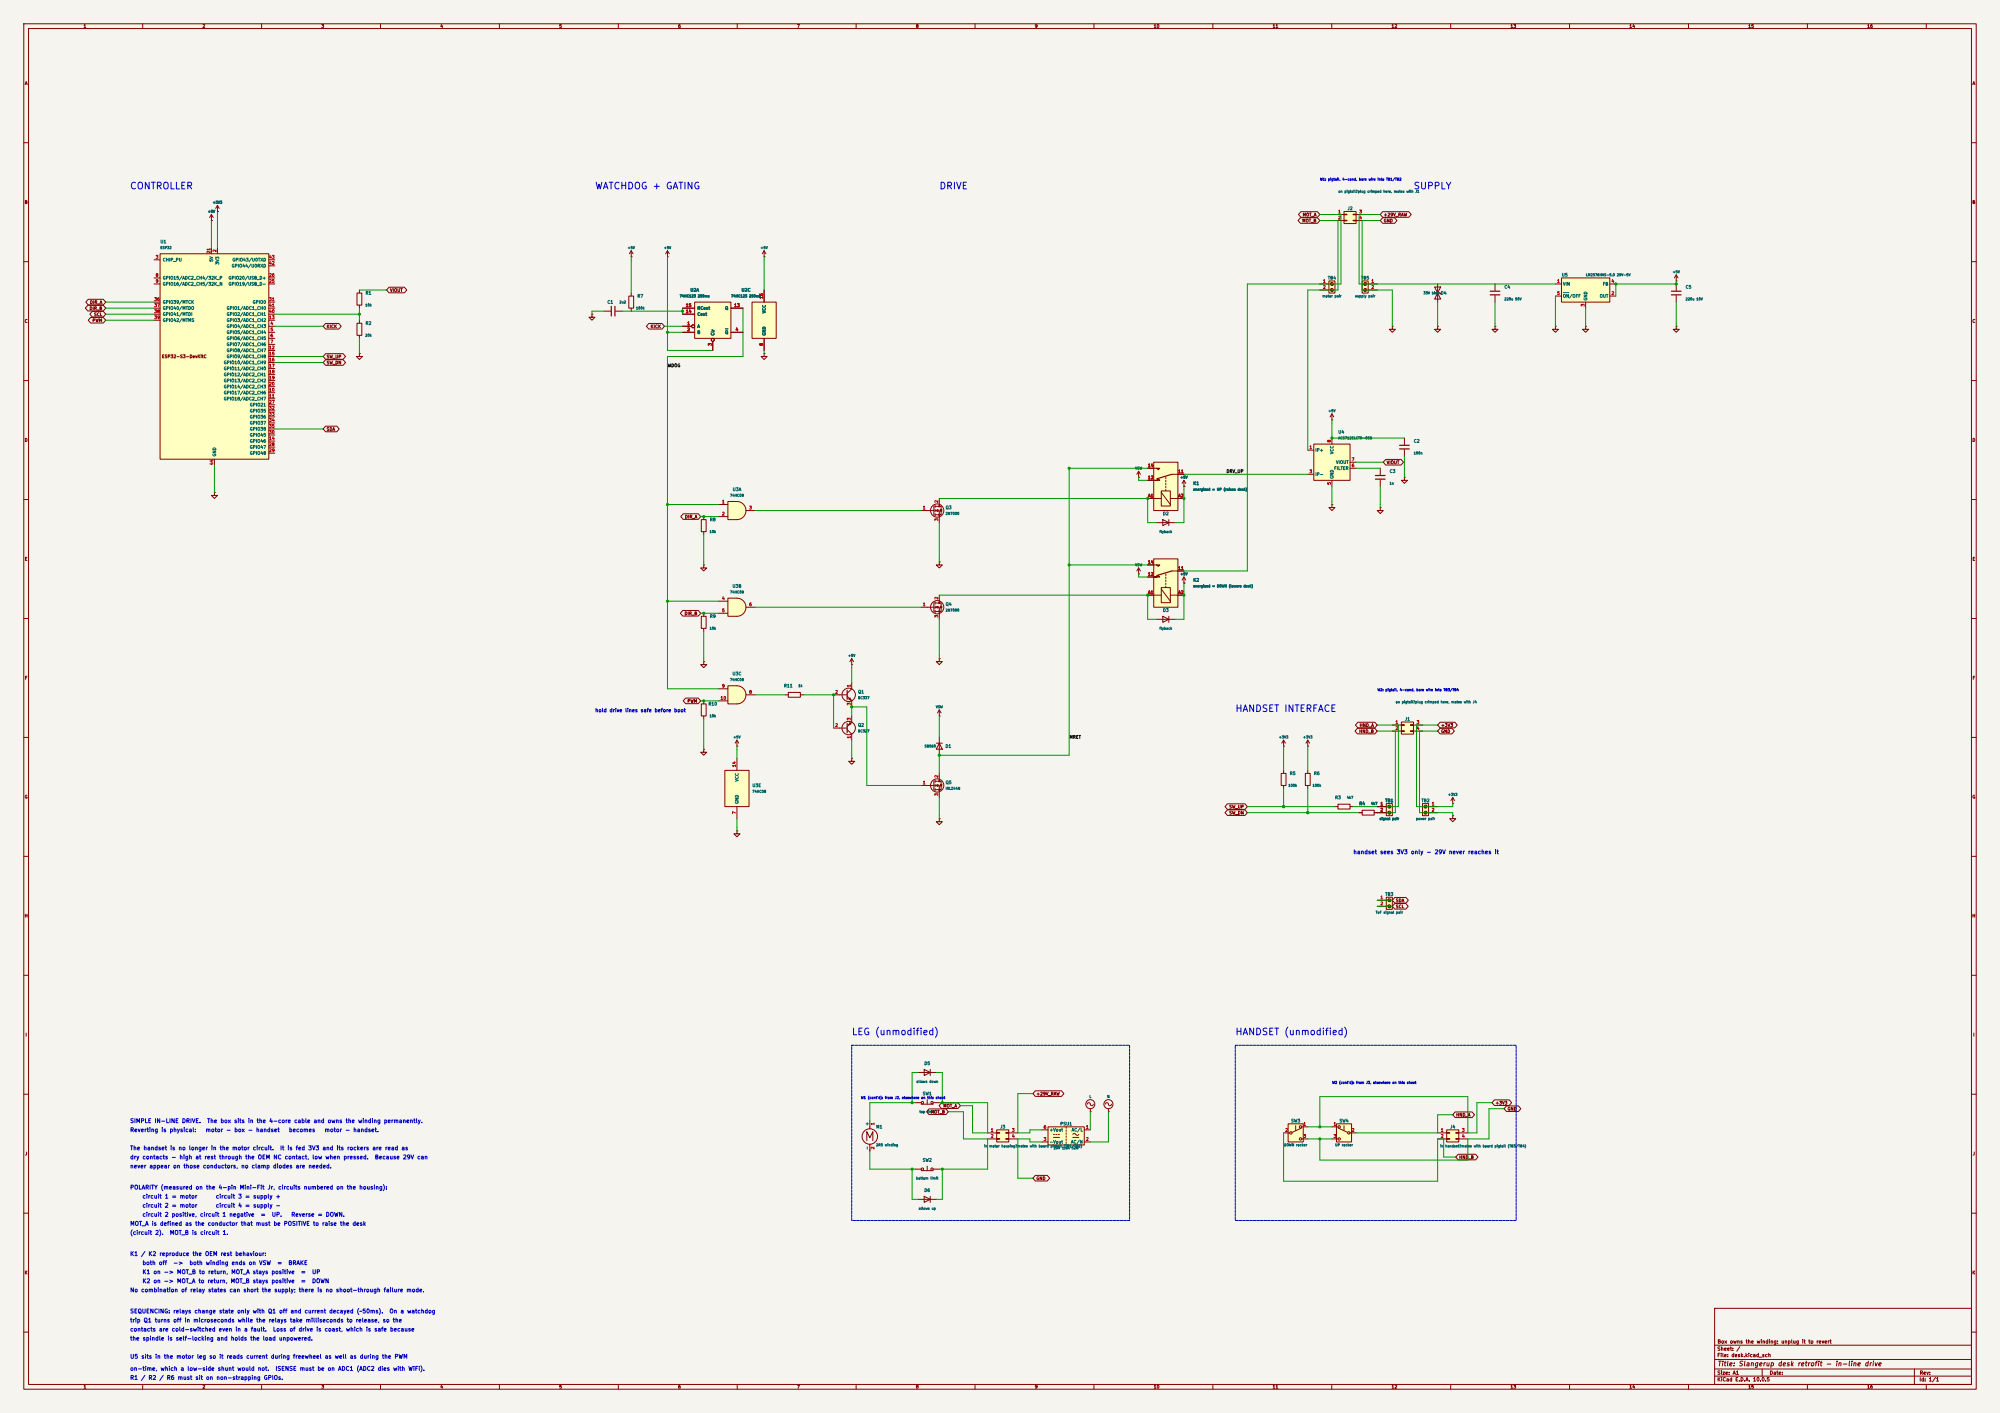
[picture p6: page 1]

W1: pigtail, 4-cond, bare wire into TB1/TB2

energized = UP (raises desk) 11

energized = UP (raises desk)

energized = DOWN (lowers desk) R8

energized = DOWN (lowers desk) 11

plug crimped here, mates with J4 R9

W2: pigtail, 4-cond, bare wire into TB3/TB4

hold drive lines safe before boot

handset sees 3V3 only - 29V never reaches it

W2 (cont'd): from J3, elsewhere on this sheet

W1 (cont'd): from J2, elsewhere on this sheet trip Q1 turns off in microseconds while the relays take milliseconds to release, so the

mates with board pigtail (TB1/TB2) SW1

POLARITY (measured on the 4-pin Mini-Fit Jr, circuits numbered on the housing):

MOT_A is defined as the conductor that must be POSITIVE to raise the desk

K1 / K2 reproduce the OEM rest behaviour:

No combination of relay states can short the supply; there is no shoot-through failure mode.

the spindle is self-locking and holds the load unpowered.

Box owns the winding; unplug it to revert
Sheet: /
File: desk.kicad_sch
Title: Slangerup desk retrofit - in-line drive

U5 sits in the motor leg so it reads current during freewheel as well as during the PWM

Size: A1 | Rev:
KiCad E.D.A. 10.0.5 | Id: 1/1

R1 / R2 / R6 must sit on non-strapping GPIOs.

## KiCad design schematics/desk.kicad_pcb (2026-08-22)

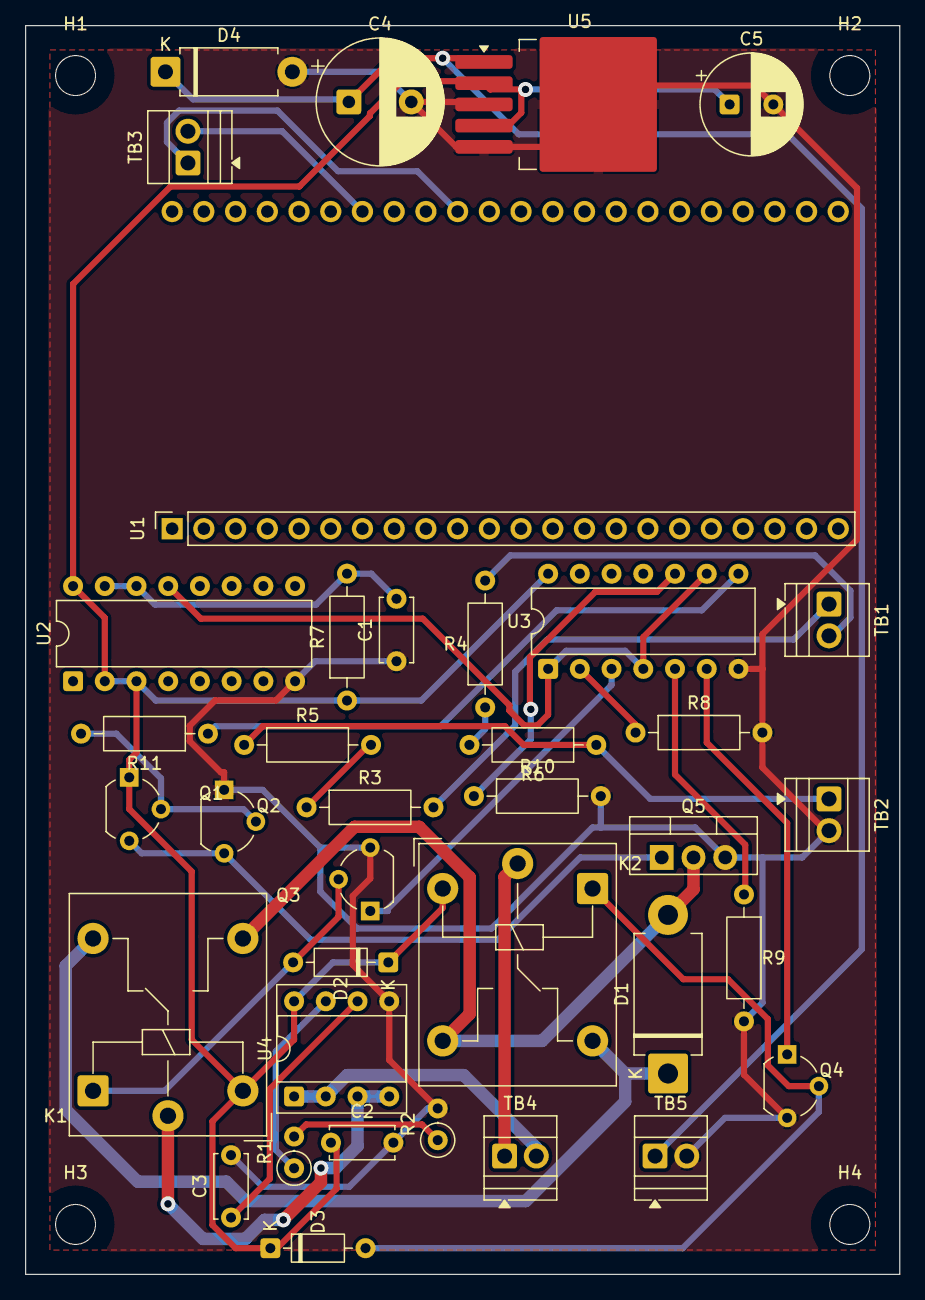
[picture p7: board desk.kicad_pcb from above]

Board: 2 copper layers, 70.0 x 100.0 mm, 41 parts (0 on the bottom side), 30 nets.

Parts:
C1: 2u2; C_Disc_D5.0mm_W2.5mm_P5.00mm
C2: 100n; C_Disc_D5.0mm_W2.5mm_P5.00mm
C3: 1n; C_Disc_D5.0mm_W2.5mm_P5.00mm
C4: 220u 50V; CP_Radial_D10.0mm_P5.00mm
C5: 220u 10V; CP_Radial_D8.0mm_P3.50mm
D1: SB560; D_DO-201AD_P12.70mm_Horizontal
D2, D3: flyback; D_DO-35_SOD27_P7.62mm_Horizontal
D4: 33V bidir; D_DO-15_P10.16mm_Horizontal
H1, H2, H3, H4: MountingHole_3.2mm_M3
K1: energized = UP (raises desk); Relay_SPDT_Hongfa_JQC-3FF_0XX-1Z
K2: energized = DOWN (lowers desk); Relay_SPDT_Hongfa_JQC-3FF_0XX-1Z
Q1: BC337; TO-92_Wide
Q2: BC327; TO-92_Wide
Q3, Q4: 2N7000; TO-92_Wide
Q5: IRLZ44N; TO-220-3_Vertical
R1: 10k; R_Axial_DIN0207_L6.3mm_D2.5mm_P2.54mm_Vertical
R2: 20k; R_Axial_DIN0207_L6.3mm_D2.5mm_P2.54mm_Vertical
R3, R4: 4k7; R_Axial_DIN0207_L6.3mm_D2.5mm_P10.16mm_Horizontal
R5, R6, R7: 100k; R_Axial_DIN0207_L6.3mm_D2.5mm_P10.16mm_Horizontal
R8, R9, R10: 10k; R_Axial_DIN0207_L6.3mm_D2.5mm_P10.16mm_Horizontal
R11: 1k; R_Axial_DIN0207_L6.3mm_D2.5mm_P10.16mm_Horizontal
TB1: signal pair; TerminalBlock_Xinya_XY308-2.54-2P_1x02_P2.54mm_Horizontal
TB2: power pair; TerminalBlock_Xinya_XY308-2.54-2P_1x02_P2.54mm_Horizontal
TB3: ToF signal pair; TerminalBlock_Xinya_XY308-2.54-2P_1x02_P2.54mm_Horizontal
TB4: motor pair; TerminalBlock_Xinya_XY308-2.54-2P_1x02_P2.54mm_Horizontal
TB5: supply pair; TerminalBlock_Xinya_XY308-2.54-2P_1x02_P2.54mm_Horizontal
U1: DevKitC_2x22_P2.54mm_1in_row
U2: 74HC123 250ms; DIP-16_W7.62mm
U3: 74HC08; DIP-14_W7.62mm
U4: ACS712ELCTR-05B; DIP-8_W7.62mm_Socket
U5: LM2576HVS-5.0 29V-5V; TO-263-5_TabPin3

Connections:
+3V3: R5.1, R6.1, TB2.1
+5V: C2.1, C5.1, D2.1 (K), D3.1 (K), K1.A2, K2.A2, Q1.1, R7.1, U2.2 (B), U2.3 (Clr), U2.16 (VCC), U3.14 (VCC), U4.8, U5.2, U5.4
/DRV_UP: K1.11, U4.3, U4.4
/MRET: D1.2 (A), K1.14, K2.14, Q5.2 (D)
/WDOG: U2.13 (Q), U3.1, U3.4, U3.9
DIR_A: R8.1, U3.2
DIR_B: R9.1, U3.5
GND: C1.1, C2.2, C3.2, C4.2, C5.2, D4.2, Q2.1, Q3.3, Q4.3, Q5.3 (S), R2.2, R8.2, R9.2, R10.2, TB2.2, TB5.2, U2.8 (GND), U3.7 (GND), U4.5, U5.3, U5.5
ISENSE: R1.2, R2.1
unnamed: D2.2 (A), K1.A1, Q3.2
unnamed: D3.2 (A), K2.A1, Q4.2
unnamed: Q1.3, Q2.3, Q5.1 (G)
unnamed: Q3.1, U3.3
unnamed: Q4.1, U3.6
unnamed: Q1.2, Q2.2, R11.2
unnamed: R11.1, U3.8
unnamed: K2.11, TB4.1
unnamed: TB4.2, U4.1, U4.2
unnamed: C4.1, D4.1, TB5.1, U5.1
unnamed: R3.2, TB1.1
unnamed: R4.2, TB1.2
unnamed: C1.2, R7.2, U2.14 (Cext), U2.15 (RCext)
unnamed: C3.1, U4.6
unnamed: R1.1, U4.7
PWM: R10.1, U3.10
SCL: TB3.2, U1.38
SDA: TB3.1, U1.35
SW_DN: R4.1, R6.2
SW_UP: R3.1, R5.2
VSW: D1.1 (K), K1.12, K2.12

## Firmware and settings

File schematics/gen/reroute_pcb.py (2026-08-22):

#!/usr/bin/env python3
"""Strip routing from ../desk.kicad_pcb and re-route it from scratch.

For experimenting with placement: drag footprints around in KiCad's PCB
editor (or move them via the pcbnew API), save, then run this script. It
throws away all existing tracks/vias/zones, re-routes with Freerouting,
widens any undersized SMD-fanout stub and drops any single-layer
dangling via Freerouting's own fanout stage leaves behind, and refills
both ground pours plus a keepout around every mounting hole
(MOUNTING_HOLE_KEEPOUT_MM) - the same manual sequence this session used
for every placement change, now in one command.

Does NOT touch footprint positions, the board outline, or anything else -
only tracks, vias, and zones (the two GND pours and the mounting-hole
keepouts). Re-run after every placement change you want to test.

Usage (from schematics/gen/):
    python3 reroute_pcb.py [--passes N]

Requires:
    - Freerouting jar installed at the path below (KiCad plugin manager,
      "Freerouting" plugin)
    - Java on PATH
    - pcbnew Python module (comes with the KiCad install)

Implementation note: each pcbnew-touching step below runs as its own
`python3 -c ...` subprocess rather than inline in this process. Chaining
multiple LoadBoard/Remove/Export/Import calls within a single long-lived
pcbnew session corrupts the SWIG bindings after a few operations (this
KiCad build) - AttributeErrors on a previously-fine BOARD object, for no
apparent reason tied to code order. One pcbnew call per process sidesteps
it entirely, matching how this whole PCB layout was developed by hand.
"""
import argparse
import ast
import os
import re
import shutil
import subprocess
import sys
import tempfile

PCB_PATH = os.path.abspath(os.path.join(os.path.dirname(__file__), "..", "desk.kicad_pcb"))
# .kicad_pro is gitignored (never version-controlled) - it holds real,
# hand-set DRC rules (0.4mm clearance etc.) that don't live in the .kicad_pcb
# itself. Loading a board from one path and Save()-ing it to another where a
# .kicad_pro already exists causes pcbnew to silently overwrite that project
# file with in-memory defaults (observed directly: min_clearance 0.4 -> 0.0,
# min_track_width 0.5 -> 0.2, after nothing more than a LoadBoard+Save
# round-trip through a temp copy). Since there's no git history to recover
# it from, back it up before touching anything and restore it unconditionally
# when done, regardless of what pcbnew's Save() calls did to it.
PRO_PATH = os.path.abspath(os.path.join(os.path.dirname(__file__), "..", "desk.kicad_pro"))
FREEROUTING_JAR = os.path.expanduser(
    "~/.local/share/kicad/10.0/3rdparty/plugins/"
    "app_freerouting_kicad-plugin/jar/freerouting-2.3.0.jar"
)

# Must match the board's real netclass rules (board setup -> Design Rules).
# ExportSpecctraDSN always writes generic 0.2mm/0.2mm/0.6mm-0.3mm-via
# defaults regardless of the actual netclass, so these get patched in.
TRACK_WIDTH_MM = 0.5
CLEARANCE_MM = 0.4
VIA_PAD_MM = 1.2
VIA_DRILL_MM = 0.6

# Motor-current-carrying nets get a wider trace than the generic
# TRACK_WIDTH_MM signal default - checked directly against pcbnew (see
# conversation): the whole board was a uniform 0.5mm, which a standard
# IPC-2221 external-layer/1oz-copper table puts at roughly 1A for a sane
# thermal rise, undersized for this design's measured 1.8A supply
# (current-limited, but "2 min continuous at half load" is a real,
# documented duty mode, not just brief pulses). 1.0mm covers 1.8A with
# real margin. These have to be their own Specctra DSN class (pulled out
# of kicad_default's member list below), not just a bigger number
# patched into the global (width 500) after export - a uniform widen-
# in-place attempt broke clearance against neighbouring pads in the
# tightly-packed relay/diode cluster (K1/K2/D2), which was already
# routed right at the 0.4mm clearance limit at 0.5mm width. Freerouting
# needs the wider requirement as an actual per-net rule so it can find
# valid paths around that, not have it forced on afterward.
POWER_TRACK_WIDTH_MM = 1.0
POWER_NETS = ("VSW", "/MRET", "/DRV_UP", "Net-(TB1-Pin_1)", "Net-(TB1-Pin_2)")

ZONE_CLEARANCE_MM = 0.4
ZONE_THERMAL_GAP_MM = 0.3
BOARD_MARGIN_MM = 2.0

# MountingHole_* footprints (H1-H4) use a single NPTH pad (no copper
# annulus) with no keepout zone of their own - checked directly (see
# conversation): the GND pour was filling to within ~0.3mm of the drill
# edge, just the zone's own generic clearance setting, not a real
# mechanical keepout. A common M3 screw/washer head (~6mm) needs about
# 1.4mm past the 3.2mm drill edge to actually clear copper. This is a
# rule-area keepout (no copper fill, any layer), not just a wider
# clearance number, so it survives regardless of zone settings.
MOUNTING_HOLE_KEEPOUT_MM = 6.5


def run_py(code):
    """Run `code` as a standalone python3 subprocess and return stdout."""
    result = subprocess.run([sys.executable, "-c", code], capture_output=True, text=True)
    if result.returncode != 0:
        sys.exit(f"subprocess failed:\n{result.stdout}\n{result.stderr}")
    return result.stdout


def check_overlaps(src_path):
    # Courtyard-only, not full bounding box: silkscreen overlaps are expected
    # and accepted on this board (irrelevant for a self-milled design) - only
    # a real F.Courtyard overlap indicates parts that would physically collide.
    out = run_py(f"""
import pcbnew
b = pcbnew.LoadBoard({src_path!r})

def courtyard_bbox(fp):
    bbox = None
    for item in fp.GraphicalItems():
        if item.GetLayerName() == 'F.Courtyard':
            bb = item.GetBoundingBox()
            l, t, r, bo = bb.GetLeft(), bb.GetTop(), bb.GetRight(), bb.GetBottom()
            if bbox is None:
                bbox = [l, t, r, bo]
            else:
                bbox = [min(bbox[0], l), min(bbox[1], t), max(bbox[2], r), max(bbox[3], bo)]
    return bbox

def intersects(a, c):
    return not (a[2] <= c[0] or c[2] <= a[0] or a[3] <= c[1] or c[3] <= a[1])

fps = list(b.GetFootprints())
boxes = [(fp.GetReference(), courtyard_bbox(fp)) for fp in fps]
boxes = [(ref, bb) for ref, bb in boxes if bb is not None]
overlaps = [(boxes[i][0], boxes[j][0])
            for i in range(len(boxes)) for j in range(i+1, len(boxes))
            if intersects(boxes[i][1], boxes[j][1])]
print(overlaps)
""")
    overlaps = ast.literal_eval(out.strip().splitlines()[-1])
    if overlaps:
        sys.exit(f"Footprint courtyard overlaps found, fix placement first: {overlaps}")


def strip_routing(src_path, dst_path):
    run_py(f"""
import pcbnew
b = pcbnew.LoadBoard({src_path!r})
for t in list(b.Tracks()):
    b.Remove(t)
for z in list(b.Zones()):
    b.Remove(z)
b.Save({dst_path!r})
""")


def board_outline_mm(src_path):
    out = run_py(f"""
import pcbnew
b = pcbnew.LoadBoard({src_path!r})
edges = [d for d in b.GetDrawings() if d.GetLayer() == pcbnew.Edge_Cuts]
minx = min(pcbnew.ToMM(d.GetBoundingBox().GetLeft()) for d in edges)
miny = min(pcbnew.ToMM(d.GetBoundingBox().GetTop()) for d in edges)
maxx = max(pcbnew.ToMM(d.GetBoundingBox().GetRight()) for d in edges)
maxy = max(pcbnew.ToMM(d.GetBoundingBox().GetBottom()) for d in edges)
print(minx, miny, maxx, maxy)
""")
    return tuple(float(v) for v in out.strip().splitlines()[-1].split())


def export_and_patch_dsn(src_path, dsn_path):
    run_py(f"""
import pcbnew
b = pcbnew.LoadBoard({src_path!r})
ok = pcbnew.ExportSpecctraDSN(b, {dsn_path!r})
assert ok, "ExportSpecctraDSN failed"
""")
    content = open(dsn_path).read()
    m = re.search(r"Via\[0-1\]_(\d+):(\d+)_um", content)
    if not m:
        sys.exit("could not find via padstack in exported DSN")
    old_dia = m.group(1)
    via_pad_um = int(VIA_PAD_MM * 1000)
    via_drill_um = int(VIA_DRILL_MM * 1000)
    content = content.replace(m.group(0), f"Via[0-1]_{via_pad_um}:{via_drill_um}_um")
    content = content.replace(f"(circle F.Cu {old_dia})", f"(circle F.Cu {via_pad_um})")
    content = content.replace(f"(circle B.Cu {old_dia})", f"(circle B.Cu {via_pad_um})")
    content = content.replace("(width 200)", f"(width {int(TRACK_WIDTH_MM * 1000)})")
    content = content.replace("(clearance 200)", f"(clearance {int(CLEARANCE_MM * 1000)})")
    content = _split_power_class(content, via_pad_um, via_drill_um)
    open(dsn_path, "w").write(content)


def _dsn_token(net):
    # Specctra DSN quotes any net name containing characters that aren't
    # plain identifier chars (Kicad's own exporter already does this for
    # the member lists being patched here - matched, not reinvented).
    return f'"{net}"' if re.search(r"[^A-Za-z0-9_+/-]", net) else net


def _find_matching_paren(content, open_pos):
    """content[open_pos] must be '(' - return the index just past its
    matching ')'."""
    depth = 0
    for i in range(open_pos, len(content)):
        if content[i] == "(":
            depth += 1
        elif content[i] == ")":
            depth -= 1
            if depth == 0:
                return i + 1
    sys.exit("unbalanced parens scanning DSN class block")


def _split_power_class(content, via_pad_um, via_drill_um):
    # Pull POWER_NETS out of kicad_default's member list into their own
    # class with a wider (rule (width ...)) - a class-level rule is what
    # Freerouting actually routes to; patching the global width after
    # export (like the plain TRACK_WIDTH_MM case above) can't give some
    # nets a different width than others.
    start = content.find("(class kicad_default")
    if start == -1:
        sys.exit("could not find kicad_default class in exported DSN")
    end = _find_matching_paren(content, start)
    block = content[start:end]

    members_m = re.search(r"\(class kicad_default((?:.|\n)*?)\(circuit", block)
    members = members_m.group(1)
    trimmed = members
    for net in POWER_NETS:
        token = _dsn_token(net)
        trimmed, n = re.subn(r"\s+" + re.escape(token) + r"(?=\s)", "", trimmed,
                              count=1)
        if not n:
            sys.exit(f"power net {net!r} not found in kicad_default class - "
                      f"check it's actually present on this board")
    block = block.replace(f"(class kicad_default{members}(circuit",
                          f"(class kicad_default{trimmed}(circuit", 1)

    power_members = " ".join(_dsn_token(n) for n in POWER_NETS)
    power_width_um = int(POWER_TRACK_WIDTH_MM * 1000)
    power_class = (
        f"\n    (class power_nets {power_members}\n"
        f"      (circuit\n"
        f'        (use_via "Via[0-1]_{via_pad_um}:{via_drill_um}_um")\n'
        f"      )\n"
        f"      (rule\n"
        f"        (width {power_width_um})\n"
        f"        (clearance {int(CLEARANCE_MM * 1000)})\n"
        f"      )\n"
        f"    )"
    )
    # Insert the new class right after kicad_default's own closing paren -
    # still inside the enclosing (network ...) block, as a sibling class,
    # not after it (that would be a syntax error Freerouting can't parse).
    return content[:start] + block + power_class + content[end:]


def run_freerouting(dsn_path, ses_path, passes):
    if not os.path.exists(FREEROUTING_JAR):
        sys.exit(f"Freerouting jar not found at {FREEROUTING_JAR}")
    result = subprocess.run(
        [
            "java", "-Djava.awt.headless=true", "-jar", FREEROUTING_JAR,
            "-de", dsn_path, "-do", ses_path, "-mp", str(passes),
        ],
        capture_output=True, text=True, timeout=300,
    )
    log = result.stdout + result.stderr
    print(log[-1500:])
    m = re.findall(r"(\d+) unrouted and (\d+) violations", log)
    if not m or m[-1] != ("0", "0"):
        sys.exit("Freerouting did not fully complete - see log above")


def import_ses_and_zone(clean_path, ses_path, out_path):
    out = run_py(f"""
import pcbnew

b = pcbnew.LoadBoard({clean_path!r})
ok = pcbnew.ImportSpecctraSES(b, {ses_path!r})
assert ok, "ImportSpecctraSES failed"

# Freerouting's own SMD-pin fanout stage (escaping a surface-mount pad
# onto the routing grid) doesn't reliably respect the DSN width rule -
# checked directly (see conversation, U1's TO-263-5 swap): 3 short stub
# segments came back at 0.375mm against this board's 0.5mm netclass
# floor. Width is a floor-only fix (never narrows a wider, intentional
# power-net segment - see POWER_TRACK_WIDTH_MM above - only ever raises
# a too-thin one up to the base minimum).
min_width = pcbnew.FromMM({TRACK_WIDTH_MM})
widened = 0
for t in b.Tracks():
    if t.Type() == pcbnew.PCB_TRACE_T and t.GetWidth() < min_width:
        t.SetWidth(min_width)
        widened += 1
if widened:
    print(f"widened {{widened}} undersized fanout stub(s) to {TRACK_WIDTH_MM}mm")

# Same fanout stage sometimes leaves a via that only ever touches copper
# (track or filled zone) on ONE of its two spanned layers - provably not
# completing a layer transition (also checked directly: one such via
# had 2 F.Cu tracks and zero B.Cu tracks). Safe to remove: if it were
# carrying the net across layers, the other layer would show it.
def _touches_layer(b, pos, net, layer_name):
    for t in b.Tracks():
        if (t.Type() == pcbnew.PCB_TRACE_T and t.GetNetname() == net
                and t.GetLayerName() == layer_name
                and (min((t.GetStart() - pos).EuclideanNorm(),
                         (t.GetEnd() - pos).EuclideanNorm()) < 1000)):
            return True
    layer_id = pcbnew.F_Cu if layer_name == "F.Cu" else pcbnew.B_Cu
    for zone in b.Zones():
        if (not zone.GetIsRuleArea() and zone.IsOnLayer(layer_id)
                and zone.GetNetname() == net
                and zone.HitTestFilledArea(layer_id, pos)):
            return True
    for fp in b.GetFootprints():
        for pad in fp.Pads():
            if (pad.GetNetname() == net
                    and layer_id in pad.GetLayerSet().Seq()
                    and (pad.GetPosition() - pos).EuclideanNorm() < 1000):
                return True
    return False

dangling = [v for v in list(b.Tracks()) if v.Type() == pcbnew.PCB_VIA_T
            and not (_touches_layer(b, v.GetPosition(), v.GetNetname(), "F.Cu")
                     and _touches_layer(b, v.GetPosition(), v.GetNetname(), "B.Cu"))]
for v in dangling:
    b.Remove(v)
if dangling:
    print(f"removed {{len(dangling)}} dangling via(s) touching only one copper layer")

b.Save({out_path!r})
n_tracks = sum(1 for t in b.Tracks() if t.Type() == pcbnew.PCB_TRACE_T)
n_vias = sum(1 for t in b.Tracks() if t.Type() == pcbnew.PCB_VIA_T)
print(n_tracks, n_vias)
""")
    n_tracks, n_vias = out.strip().splitlines()[-1].split()
    print(f"Routed: {{n_tracks}} tracks, {{n_vias}} vias".format(n_tracks=n_tracks, n_vias=n_vias))

    minx, miny, maxx, maxy = board_outline_mm(out_path)
    m = BOARD_MARGIN_MM
    x0, y0, x1, y1 = minx + m, miny + m, maxx - m, maxy - m

    run_py(f"""
import pcbnew
import math
b = pcbnew.LoadBoard({out_path!r})

# Keepouts first, so the GND pour fill below already avoids them on its
# one and only fill pass - order matters, filler.Fill() runs once at the
# end of this block.
mounting_holes = [fp.GetPosition() for fp in b.GetFootprints()
                  if str(fp.GetFPID().GetLibItemName()).startswith("MountingHole")]
r = pcbnew.FromMM({MOUNTING_HOLE_KEEPOUT_MM} / 2)
for i, hpos in enumerate(mounting_holes):
    zone = pcbnew.ZONE(b)
    layers = pcbnew.LSET()
    layers.AddLayer(pcbnew.F_Cu)
    layers.AddLayer(pcbnew.B_Cu)
    zone.SetLayerSet(layers)
    zone.SetIsRuleArea(True)
    zone.SetDoNotAllowZoneFills(True)
    zone.SetDoNotAllowTracks(True)
    zone.SetDoNotAllowVias(True)
    zone.SetDoNotAllowPads(False)  # else it flags the mounting hole's own NPTH pad
    zone.SetZoneName(f"mounting_hole_keepout_{{i}}")
    outline = zone.Outline()
    outline.NewOutline()
    for seg in range(32):
        ang = 2 * math.pi * seg / 32
        outline.Append(int(hpos.x + r * math.cos(ang)), int(hpos.y + r * math.sin(ang)))
    b.Add(zone)

for layer, name in [(pcbnew.F_Cu, "GND_POUR"), (pcbnew.B_Cu, "GND_POUR_B")]:
    zone = pcbnew.ZONE(b)
    zone.SetLayer(layer)
    zone.SetNetCode(b.GetNetcodeFromNetname("GND"))
    zone.SetZoneName(name)
    outline = zone.Outline()
    outline.NewOutline()
    for px, py in [({x0}, {y0}), ({x1}, {y0}), ({x1}, {y1}), ({x0}, {y1})]:
        outline.Append(int(pcbnew.FromMM(px)), int(pcbnew.FromMM(py)))
    zone.SetIsFilled(False)
    zone.SetLocalClearance(pcbnew.FromMM({ZONE_CLEARANCE_MM}))
    zone.SetThermalReliefGap(pcbnew.FromMM({ZONE_THERMAL_GAP_MM}))
    # keep disconnected fill fragments (deliberate: cheaper to mill solid
    # copper than bare board carved out of the same area)
    zone.SetIslandRemovalMode(pcbnew.ISLAND_REMOVAL_MODE_NEVER)
    b.Add(zone)

filler = pcbnew.ZONE_FILLER(b)
filler.Fill(b.Zones())
b.Save({out_path!r})
""")


def main():
    ap = argparse.ArgumentParser()
    ap.add_argument("--passes", type=int, default=10, help="Freerouting max passes")
    args = ap.parse_args()

    pro_backup = None
    if os.path.exists(PRO_PATH):
        pro_backup = PRO_PATH + ".reroute-backup"
        shutil.copy2(PRO_PATH, pro_backup)

    try:
        with tempfile.TemporaryDirectory() as tmp:
            check_overlaps(PCB_PATH)

            clean_path = os.path.join(tmp, "clean.kicad_pcb")
            strip_routing(PCB_PATH, clean_path)

            print(f"Routing {board_outline_mm(clean_path)} board...")

            dsn_path = os.path.join(tmp, "route.dsn")
            ses_path = os.path.join(tmp, "route.ses")
            export_and_patch_dsn(clean_path, dsn_path)

            run_freerouting(dsn_path, ses_path, args.passes)

            import_ses_and_zone(clean_path, ses_path, PCB_PATH)
            print(f"Saved {PCB_PATH}")
    finally:
        if pro_backup:
            shutil.move(pro_backup, PRO_PATH)
            print(f"Restored {PRO_PATH} (pcbnew's Save() calls can clobber it - see comment at top)")

    print("Run `kicad-cli pcb drc --severity-all desk.kicad_pcb` from schematics/ to verify.")


if __name__ == "__main__":
    main()

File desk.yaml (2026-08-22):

# Example ESPHome config using the custom desk component.
# Place this next to a `my_components/` folder containing desk/.

esphome:
  name: standing-desk

esp32:
  board: esp32-s3-devkitc-1  # verify against the exact N16R8 variant received
  framework:
    type: esp-idf

external_components:
  - source:
      type: local
      path: my_components
    components: [desk]

wifi: !include wifi.yaml
logger:
api:
ota:
  - platform: esphome

# 20 kHz: above audible, and short compared with the winding's L/R.
output:
  - platform: ledc
    id: motor_pwm
    pin: GPIO42            # PWM, see schematics/gen/sch.py SIGNAL_GPIO
    frequency: 20000Hz

cover:
  - platform: desk
    name: "Standing desk"
    id: desk1
    pwm: motor_pwm
    relay_up:
      number: GPIO39       # DIR_A
      inverted: false      # fixed by this board's own drive polarity, see README §7.3/§6.3
    relay_down:
      number: GPIO40       # DIR_B
      inverted: false
    watchdog_pin: GPIO4    # KICK
    current_pin: 2         # ISENSE, ADC1_CHANNEL_1 on the S3 - ADC2 is unusable with WiFi
    ramp_up_ms: 500
    ramp_down_ms: 300
    settle_ms: 50
    travel_mm: 500
    speed_mm_s: 25.0
    max_run_ms: 25000
    stall_current: 2.2

sensor:
  - platform: template
    name: "Desk current"
    unit_of_measurement: A
    accuracy_decimals: 2
    update_interval: 1s
    lambda: 'return id(desk1).current_amps();'

# The OEM rockers, read as active-low dry contacts.
binary_sensor:
  - platform: gpio
    id: rocker_up
    pin: {number: GPIO9, mode: INPUT_PULLUP, inverted: true}   # SW_UP
    on_press:
      then: [cover.open: desk1]
    on_release:
      then: [cover.stop: desk1]
  - platform: gpio
    id: rocker_down
    pin: {number: GPIO10, mode: INPUT_PULLUP, inverted: true}  # SW_DN
    on_press:
      then: [cover.close: desk1]
    on_release:
      then: [cover.stop: desk1]

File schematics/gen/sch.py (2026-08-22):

#!/usr/bin/env python3
"""desk - Jysk Slangerup desk retrofit, in-line drive.

No transfer relay and no in-place fallback. The box sits in the 4-core
cable and permanently owns the winding; the handset is permanently fed
3V3 and its rockers are plain inputs.

Reverting is physical: motor - box - handset  becomes  motor - handset.
"""
import sys  # noqa: E402

from symbols import (Schematic, GNDS, RAILS, _rail, R_, C_, DH,  # noqa: E402
                     TVS, NMOS, MOT, LIM, RLY, BUCK, MCU, GPIO_PIN,
                     MCU_5V, MCU_GND, MCU_3V3, MONO, AND2,
                     BJT_NPN, BJT_PNP, ACS, CONN, PSU, AC_FLAG, ROCKER, TERM2,
                     JP4)

s = Schematic("desk", "Slangerup desk retrofit - in-line drive",
              "Box owns the winding; unplug it to revert", paper="A1")

_n = [0]


def _uref():
    _n[0] += 1
    return f"#PWR{_n[0]:03d}"


def gnd_tap(x, y):
    # Nudge is a full grid step (1.27), not 1mm - snap() rounds both
    # endpoints to the nearest grid point, and a 1mm nudge sometimes
    # rounds to the SAME point as its own start (whenever y falls in the
    # part of its grid cell where +1mm doesn't cross the rounding
    # boundary), producing an invisible zero-length wire. Adding exactly
    # one grid step always lands one step over, never the same point.
    s.place(GNDS, _uref(), "GND", x, y + 1.27, hide_ref=True, hide_val=True)
    s.wire((x, y), (x, y + 1.27))


def tap(x, y, name):
    if name not in RAILS:
        RAILS[name] = _rail(name)
    s.place(RAILS[name], _uref(), name, x, y - 1.27, hide_ref=True)
    s.wire((x, y), (x, y - 1.27))


def pigtail_break(pin, net_name, note, dx1, dy, dx2):
    # J2/J3 (the board-side Mini-Fits) aren't drawn (see symbols.py) - the
    # pigtail that used to mate with them is real, off-board wire, so
    # TB1-4 and J1/J4 need an actual net link across that gap, not just
    # the prose that used to be the only connection (see conversation).
    # A matching glabel is the standard KiCad way to say "this net
    # continues somewhere else on the page" - dx1 first (perpendicular
    # to whatever axis the pin's own existing wire already uses, so this
    # new branch can never be mistaken for a continuation of it), then
    # dy to clear the local clutter, then dx2 into the label itself so
    # every label in this file keeps the same horizontal-approach shape
    # (angle 0/180 - see RIGHT_SIDE/LEFT_SIDE above).
    #
    # Two pins of the same 2-pin part share one x column (only their y
    # differs, by the part's own pitch). Calling this on both with the
    # same dx1 puts both rises on that exact column - dy (8+) dwarfs a
    # 2.54 pitch, so the two rises don't just run parallel nearby, they
    # overlap on the SAME line: a dead short between two different
    # nets, not a visual nicety fixed by matching dy. dx1 must differ
    # between the two calls (0 and something else entirely) so the two
    # rises are never on the same column in the first place.
    x0, y0 = pin
    x1 = x0 + dx1
    y1 = y0 - dy
    x2 = x1 + dx2
    s.wire((x0, y0), (x1, y0), (x1, y1), (x2, y1))
    ang = 0 if dx2 >= 0 else 180
    s.glabel(net_name, x2, y1, angle=ang)
    if note:
        nx = x2 + 1 if dx2 >= 0 else x2 - 1 - 0.9 * len(note)
        s.note(note, nx, y1 - 2.5, 1.0)


V5, VS, V3 = "+5V", "VSW", "+3V3"

# ========================================================== controller ====
# Shifted 230mm left of where this whole CONTROLLER-through-DRIVE block
# used to sit, to make room for SUPPLY to move to the right instead (next
# to J2, which it now wires to directly - see SUPPLY section and
# conversation).
s.note("CONTROLLER", 55, 80, 2.8)
# Off-board: U2's own 2x22 header is a genuine copper-layer capacity
# wall on this PCB (see JP2/JP3/JP4 in symbols.py) - it lives elsewhere
# as a free-standing DevKitC, wired in over JST-XH pigtails instead of
# a footprint here.
s.place(MCU, "U1", "ESP32", 90, 150)
# U2 has no footprint on this board at all any more (see the on_board
# note above), so NONE of its pins connect by drawn PCB-shaped wiring -
# every one of them reaches the rest of the circuit either as a plain
# power-rail tap (5V/3V3/GND - already global nets, nothing pigtail-
# specific needed) or via a matching schematic label picked up by one
# of three small JST-XH connectors below, grouped by function: power,
# the four drive outputs, and the rocker/current-sense inputs. Which
# physical DevKitC pin carries which signal still matters for firmware
# (SIGNAL_GPIO below) and for wiring the real pigtail harness later,
# but no longer for PCB routing - there's no PCB copper here to route.
mcu_5v, mcu_gnd, mcu_3v3 = (s.pin("U1", MCU_5V), s.pin("U1", MCU_GND),
                            s.pin("U1", MCU_3V3))
s.wire(mcu_5v, (mcu_5v[0], mcu_5v[1] - 10))
tap(mcu_5v[0], mcu_5v[1] - 10, V5)
s.wire(mcu_gnd, (mcu_gnd[0], mcu_gnd[1] + 10))
gnd_tap(mcu_gnd[0], mcu_gnd[1] + 10)
s.wire(mcu_3v3, (mcu_3v3[0], mcu_3v3[1] - 14))
tap(mcu_3v3[0], mcu_3v3[1] - 14, V3)

# Constraints on the GPIO choice (firmware-side, unaffected by U2 no
# longer being on this PCB): avoid strapping (0/3/45/46), avoid this
# module's flash/PSRAM-reserved range (22-37 - wider than usual since
# this is an N16R8/octal-PSRAM part), avoid native USB (19/20), keep
# ISENSE on an ADC1-capable pin.
SIGNAL_GPIO = {"KICK": 4, "ISENSE": 2, "MODE": 8, "SW_UP": 9, "SW_DN": 10,
               "SDA": 38, "SCL": 41, "DIR_A": 39, "DIR_B": 40, "PWM": 42}
# SDA/SCL moved from GPIO12/13 (physical pins 18/19) to GPIO38/41
# (physical pins 35/38) - see conversation. Not a firmware-arbitrary
# choice: pins 18/19 sit in a part of U2's real footprint where the PCB
# is already at copper capacity (confirmed by both Freerouting and
# careful manual attempts failing to route out from there at all), while
# 35/38 sit immediately next to DIR_A/DIR_B/PWM (pins 36/37/39) - GPIOs
# that already route successfully from that exact neighborhood. Neither
# is strapping/PSRAM-reserved/native-USB (same constraints as before).
PIN = {sig: GPIO_PIN[g] for sig, g in SIGNAL_GPIO.items()}

OUT = {PIN["DIR_A"]: "DIR_A", PIN["DIR_B"]: "DIR_B", PIN["PWM"]: "PWM",
       PIN["MODE"]: None, PIN["KICK"]: "KICK", PIN["ISENSE"]: "ISENSE",
       PIN["SDA"]: "SDA", PIN["SCL"]: "SCL", PIN["SW_UP"]: "SW_UP",
       PIN["SW_DN"]: "SW_DN"}
pins = {k: s.pin("U1", k) for k in OUT}
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

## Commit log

2026-08-09 Initial commit: Jysk Slangerup desk retrofit design
    Reverse-engineered replacement drive electronics for a Jysk Slangerup
    electric standing desk, controlled by an ESP32 via ESPHome. Includes
    KiCad schematics (chosen design, original, and rejected variant),
    the ESPHome external component, and README documenting measurements
    and design rationale.
    [desk_inline.kicad_sch, desk_original.kicad_sch, desk_simple.kicad_sch]
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2026-08-09 Fix sch_simple.py regeneration and add schematics/Makefile
    sch_simple.py loaded its symbol library via exec() of a file
    (_sym_preamble.py) that only ever existed in the original session's
    sandbox and was never committed — the chosen design's schematic was not
    actually reproducible from its own source. Extracted the needed symbols
    into symbols.py (matching the equivalent block already inline in
    sch_inline.py) and fixed the hardcoded sandbox output paths in all three
    generators. Verified by regenerating all three .kicad_sch files and
    diffing byte-for-byte against the committed ones.
    Added a Makefile so `make` runs the full .py -> .kicad_sch -> .pdf/.svg
    chain instead of manual per-file comm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
    [symbols.py]
2026-08-15 Drop inline/original schematic variants, separate tooling from output
    The design is settled: desk_original duplicated what README §1/§2
    already document in prose, and desk_inline (design 3.3, transfer relay
    + auto fallback) was kept only for comparison while the chosen design
    was still being finished. With one sheet left, sch_simple.py/desk_simple.*
    become sch.py/desk.* since "simple" no longer distinguishes anything.
    schematics/ is now split machine vs. human: schematics/gen/ holds the
    generator and its dependencies (sch.py, schlib.py, symbols.py,
    espressif.kicad_sym, netlist_text.py, the find_*.py schematic-quality
    checkers, Makefile); schematics/ itself keeps the human-facing result
    (d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
    [desk.kicad_sch, desk_inline.kicad_sch, desk_original.kicad_sch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]
2026-08-15 Fix Q1 to IRLZ44N (30V IRLB8721 didn't clear the 29-30V rail)
    Caught by cross-checking HANDOFF.md item 7 against the actual repo:
    Q1 was still IRLB8721 despite being flagged for this exact fix (30V
    VDSS, flyback clamping puts it at/over absolute max every cycle on a
    29V nominal / 30V unloaded rail). The other half of item 7 - symbols.py
    existing with no exec() - did hold.
    Also recorded item 6 as resolved rather than open: the current sensor
    choice HANDOFF called "not yet decided" was already committed in the
    schematic (ACS724xLCTR-05AB, bidirectional 5A - exactly its own stated
    requirements) and assumed by README §4.4. Updated README §6 BOM/§6.2 to
    match current reality (IRLZ44N, discret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
    [desk.kicad_sch]
2026-08-16 Add board-side screw terminals, resolve remaining HANDOFF.md items
    Screw terminal redesign: J2/J3 (board-side Mini-Fit connectors) are
    dropped from the schematic entirely, replaced by four 2-position screw
    terminals (TB1-TB4) - the board now only ever solders to a screw
    terminal, no crimp tool needed for board assembly; a short pigtail
    carries each pair on to the actual Mini-Fit (J1/J4, unchanged). TB2/TB4
    mirrored so their pins face where their wires actually go, and moved
    clear of TB1/TB3 now that they're not physically one connector anymore.
    J1/J4 labels split across two lines (esc() extended to support literal
    newlines in Kicad property text - a small general capability, not
    J1/J4-specif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
    [desk.kicad_sch]
2026-08-16 Note the through-hole constraint in the BOM (HANDOFF item 4)
    README §6.5: this design is deliberately all through-hole (protoboard
    assembly, not a PCB house order), with a package table so substitutions
    preserve that. Adapted from HANDOFF's version for parts that changed
    since it was written - TC4427 dropped (replaced by the already-through-
    hole discrete BC337/BC327 driver).
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2026-08-16 Assign PCB footprints to every on-board part
    schlib.py: place() gains footprint= (override) and on_board= params;
    Sym now carries a per-symbol-type default footprint, set once in
    symbols.py rather than repeated at every call site (same pattern as
    ref_dy/val_dy). Per-instance overrides used where package size differs
    within one symbol type (C1/C2 electrolytic vs C3 ceramic, D5 Schottky
    vs D2/D3/D4/D6 signal diodes, Q1 TO-220 vs Q2/Q3 TO-92).
    The 10 parts that live in the motor housing/handset/wall supply - not
    on this board - are marked on_board=False (M1, J1, J4, PSU1, SW1-4,
    D3/D4) so "Update PCB from Schematic" won't try to place them.
    Two footprints are placeholders pending the physical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
    [desk.kicad_sch]
2026-08-18 Reference: single-board schematic before the logic/power PCB split
    Snapshot of the design right before splitting into two boards - U2
    (ESP32) off-board via JP1/JP2/JP3 pigtails (mated by JP4/JP5/JP6), but
    the watchdog-gated drive signals still wire straight from U6 into
    Q2/Q3/R7, and ISENSE still rides JP4's own pigtail to the ESP32, both
    as plain same-board wires (no JP7-JP12 board-tie connectors).
    Kept as a fallback in case the board-split-plus-jumpers experiment
    (continuing on main) doesn't pan out. NETLIST.md/README.md are not
    refreshed for this snapshot - schematics/gen/sch.py is the source of
    truth per its own header.
    [desk.kicad_sch]
2026-08-18 Add fully-routed 2-layer PCB for the single-board design
    Routed with KiCadRoutingTools (rust A*), F.Cu+B.Cu, at the project's real
    netclass spec (0.5mm track width, 0.4mm clearance) - no escalation to
    sub-spec traces needed. Result: 27/27 nets, 74/74 pads, 0 DRC violations,
    0 unconnected items, 46 vias.
    This directly answers the question the board-split/jumper experiment (see
    main branch's WIRING.md and README §5 item 10) was trying to answer: the
    single-board design's U6/U3 local pin-density congestion, which forced 16
    hand-jumpers on a single F.Cu layer, disappears entirely with a second
    routed layer - no split and no jumpers needed. Vias require a hand-soldered
    wire through each hole on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
    [desk.kicad_pcb]
2026-08-18 Reduce via count 46 -> 33 with placement optimization before routing
    Ran KiCadRoutingTools' place_optimize.py (greedy quench: nudges, 90-degree
    rotations, same-footprint swaps) on the unrouted placement before routing,
    locking connectors/terminal blocks (JP*/TB*) in place and ignoring GND
    (zone-poured, not a real airwire concern). Airwire crossings dropped
    96 -> 38, length 1763mm -> 1521mm; re-routing that placement (same
    settings as before: F.Cu+B.Cu, 0.5mm track, 0.4mm clearance) completed
    27/27 nets and 74/74 pads with 33 vias instead of 46 - fewer hand-soldered
    wire-throughs if self-milled, same DRC-clean result (0 electrical
    violations; 3 cosmetic silkscreen-text-overlap warnings from p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
    [desk.kicad_pcb]
2026-08-18 Re-route with Freerouting: 33 vias -> 1 via, still fully DRC-clean
    KiCadRoutingTools' placement-quench experiments (8mm/20mm displacement,
    plus the DIR_A/DIR_B gate swap) got via count down from 46 to 22 through
    successive placement improvements. Trying Freerouting (mature, JAR-based,
    via the classic Specctra DSN/SES workflow) on the ORIGINAL, un-optimized
    placement instead - no quench needed at all - produced a 1-via, 0-DRC-
    violation result outright. Its rip-up-and-reroute optimizer just handles
    via minimization far better than the grid-based A* approach.
    Gotchas hit along the way, for future reference:
    - pcbnew.ExportSpecctraDSN() does not carry over the board's real netclass
    (track wi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
    [desk.kicad_pcb]
2026-08-18 Long shot: bring U2 back on-board - works, once its footprint is fixed
    Removed the off-board ESP32 pigtail arrangement (JP1/JP2/JP3, and the
    JP4/JP5/JP6 on-board mates - kept in the schematic as on_board=False
    since their own wiring still anchors TB3/TB4/R11/R13/R14/R15's layout)
    and placed U2 directly on the board instead, wired straight to U3/U6/
    the rocker dividers/R4-R5 by matching label, the same mechanism WDOG
    already uses. Board expanded to 194x150mm to fit U2's real footprint.
    First attempt used the existing MCU.footprint - a generic 2x22 header
    with both rows only 2.54mm apart - and Freerouting got stuck at 9/68
    nets unrouted after 10 passes and 100+GB allocated, a real regression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
    [desk.kicad_pcb, desk.kicad_sch]
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2026-08-18 Re-route U2-onboard layout: 2 vias -> 0
    Ran the placement optimizer (5mm displacement) then re-routed with
    Freerouting instead of KiCadRoutingTools. Result routes fully on two
    layers with zero through-connections needed. Also picked up the
    missing B.Cu ground pour (GND_POUR_B), matching the F.Cu pour that
    was already present.
    0 unrouted, 0 unconnected, 0 real DRC violations. Remaining 8 DRC
    items are cosmetic (silkscreen reference-field overlap, thermal-relief
    spoke-count warnings on isolated pads) - same category of minor
    warnings as prior committed states, not new.
    A separate 30mm-displacement optimizer run was also tried; it moved
    30 parts (crossings 82 -> 11) but bought no further via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
    [desk.kicad_pcb]
2026-08-18 Repack layout to fit a standard 10x15cm PCB blank
    Previous layout was 194x150mm with a large empty region below the
    main component cluster (also the cause of the incomplete-ground-fill
    bug: the GND zone boundary was drawn to match the old, smaller board
    and never widened when U2 was brought on-board, so it never covered
    that area at all - see the intent behind the last commit's zone add,
    which cloned that already-undersized boundary).
    Rather than patch the boundary in place, redid placement from scratch:
    grouped parts into functional clusters (power-in, U2 + gate/watchdog
    logic, small pulldowns, FET drive, relays + current sense, motor-out
    terminal) and packed them shelf-by-shelf into a 100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
    [desk.kicad_pcb]
2026-08-18 Compact layout further: 100x150mm -> 88x123mm
    Three specific issues from eyeballing the previous layout, all fixed:
    1. U2's Value text field still read "PinSocket_1x22_P2.54mm_Vertical" -
    a leftover from the base footprint it was cloned from - rotated
    90 degrees and long enough to stretch U2's bounding box 11mm past
    its real physical extent (39.4mm tall vs the actual ~28mm). Every
    placement decision involving U2, including the whole previous
    packing pass, was working off that inflated size. Renamed to
    "ESP32_DevKitC" and put it back inside the footprint's real bounds.
    This alone explains why the U2-to-U3/U6 gap looked bigger than the
    configured 1.8mm shelf spacing.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
    [desk.kicad_pcb]
2026-08-18 Tighten ground pour clearance/thermal-relief for milling
    Both ground pours were using KiCad's stock 0.5mm zone clearance and
    0.5mm thermal-relief gap, more conservative than the board's own
    design minimum (0.4mm, already the netclass rule everything else was
    routed to). For CNC isolation milling, more contiguous copper is
    better - the mill only cuts along isolation boundaries, so needless
    clearance margin just adds boundary length for no benefit here.
    Tightened zone clearance to 0.4mm (the actual board minimum, so no
    DRC risk) and thermal-relief gap to 0.3mm (still enough moat for hand
    soldering into the pour, just less wasted area right at GND pads).
    F.Cu coverage 73.6% -> 75.7%, B.Cu 61.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
    [desk.kicad_pcb]
2026-08-18 Keep disconnected ground fill for milling instead of discarding it
    Both zones had KiCad's default "remove islands: always" setting,
    which silently discards any fill fragment that doesn't touch a GND
    pad - even when the geometry is perfectly valid and fully
    clearance-safe. That's a sane default for a fab-house board (unused
    copper serves no purpose there), but for CNC isolation milling,
    disconnected copper is still free: it needs no more cutting than
    leaving that same area bare, and it means less bare substrate
    surrounded by mandatory isolation channels around nearby traces.
    Switched both zones to "remove islands: never". Recovered coverage:
    F.Cu 75.7% -> 77.0%, B.Cu 64.1% -> 71.1% - a bigge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
    [desk.kicad_pcb]
2026-08-18 Shorten the bottom further: fix U5's inflated bounding box
    Same bug as U2 had: U5's Value text ("ACS724xLCTR-05AB") was rotated
    90 degrees and long enough to stretch its bounding box to 15.3mm tall,
    when the real component (per its courtyard) is only ~3.6mm. This
    introduced itself when I rotated U5 as a whole footprint earlier to
    shrink cluster height - the rotation carried its text along for the
    ride without me checking where the text landed afterward.
    Un-rotated the value text, shrunk it slightly, and moved it to sit
    under the part instead of trailing off below it. That row's height
    bottleneck moves to R4/R5 (12.3mm) instead of U5 (15.3mm before this
    fix) - the tallest item in that row dr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
    [desk.kicad_pcb]
2026-08-18 Give R11 more edge clearance, clean up U3's label overhang
    R11's left leg copper sat only 2.275mm from the board edge - the
    tightest of any part on the board (everything else on the left margin
    had 4mm+). Every other part in that row (R11/R13/R14/R15/R1/R2) had
    6.2mm of unused width to its right before the board edge, so shifted
    the whole row 1.7mm right: R11 now has 3.975mm of clearance, matching
    the rest of the board, at zero cost to the layout.
    Also did the full sweep for the U2/U5 text-overhang bug across every
    footprint. Found one more real case (U3's "74HC123 250ms" value,
    rotated 90 degrees, 12.8mm vs a 9.8mm courtyard) and cleaned it up,
    though it doesn't change the board outline -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
    [desk.kicad_pcb]
2026-08-18 Fix U2's row-2 pin mirroring - critical footprint bug
    The custom DevKitC footprint numbered its second row of pins (23-44)
    in the same top-to-bottom direction as row 1. Real 2-row DIP-style
    headers - confirmed against Espressif's own official ESP32-S3-DevKitC
    footprint, fetched directly from github.com/espressif/kicad-libraries -
    number row 2 bottom-to-top: pin 23 sits across from pin 22, pin 44
    across from pin 1. Every row-2 pin in this design was therefore wired
    to its mirror-image physical position.
    Impact: DIR_A, DIR_B, PWM, and ISENSE - four of this design's five
    critical control signals - all live on row 2. A real ESP32-S3-DevKitC
    plugged into a board built from the old footprint woul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
    [desk.kicad_pcb]
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2026-08-18 Rotate R3/C3, shift U6/D5/R2/TB3/TB4 left: 87x123mm -> 85.5x123mm
    R3 (12.3mm wide unrotated) and C3 (7.15mm wide unrotated) both have
    much shorter dimensions on their other axis (6.44mm and 6.7mm) - both
    fit easily within this row's height (driven by U6 at 18mm). Rotating
    them 90 degrees freed 6.32mm of width in this row, which let U6, D5,
    and R2 all shift left by that same amount.
    R2 (now closer to R1 in the rocker row) needed a slightly smaller
    shift than U6/D5 to keep 1.5mm clearance from R1 - not a uniform
    block move, adjusted per-component to the nearest real constraint.
    Once D5 stopped being the tightest thing in its row, TB3/TB4 (stacked
    at the board's right edge) became the new bin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
    [desk.kicad_pcb]
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2026-08-19 Repack using courtyard-only bounds: 85.5x123mm -> 71x105mm
    Silkscreen (reference/value text especially) doesn't matter for a
    self-milled board - no printing step, and even the K1/K2 relay
    footprints carry long descriptive Value strings ("energized = UP
    (raises desk)") that were driving their bounding box far past the
    real component body. K1 had drifted to x:-10mm (10mm off the board's
    left edge) chasing exactly this - the real courtyard was only
    4.3-20.6mm; the rest was that text field.
    Re-derived every footprint's real (courtyard-only) size and rebuilt
    placement from scratch on that basis, keeping the same functional
    clusters and orientation choices already established this session
    (TB3/TB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
    [desk.kicad_pcb]
2026-08-19 Shrink to 70x100mm - a standard pre-cut blank size
    Confirmed this will be a pre-cut blank at exactly this size, not a
    larger sheet trimmed down - so the generous 1.5-2mm edge margin used
    throughout this session (protecting copper from an imprecise hand-
    milled outline cut) doesn't apply here at all; there's no outline
    pass. Dropped to 0.5mm, matching the board's own min_copper_edge_
    clearance DRC rule instead of an arbitrary milling-safety number.
    Even so, courtyard content needed 68.0 x 100.4mm at that margin - 0.4mm
    over on height alone. Ran the quench optimizer again against a
    pre-shrunk 70x100 outline (6mm displacement, TB1-4 still locked) to
    find a fit; it got everything in except R5,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
    [desk.kicad_pcb]
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2026-08-19 Track desk.kicad_pro instead of gitignoring it
    It's been holding real, hand-set project settings for a while now -
    DRC rules (0.4mm clearance, 0.5mm track width, 0.8mm min silk text
    height) that don't live in the .kicad_pcb itself. Being gitignored
    meant no recovery path if it got corrupted, which already happened
    once this session: a pcbnew scripting round-trip (load from one path,
    save to another) silently overwrote it with stock defaults, and it had
    to be hand-fixed from values remembered earlier in the same session.
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2026-08-19 Relocate TB3/TB4 and U2 for direct USB edge access
    TB3+TB4 sat right against U2's USB-C end with only ~1mm clearance,
    and blocked any enclosure opening from reaching it. Both terminals are
    now fully internal (wired via pigtail before the enclosure is
    mounted), so their position is no longer tied to a specific board
    edge - moved them to a free pocket lower on the right side.
    That freed the space to also shift U2 itself right so the USB-C end
    sits ~1.4mm from the board's right edge (was ~11mm) for direct
    enclosure access. As a side effect this pulls U2's antenna end fully
    inside the board too, removing the previous edge overhang.
    Re-routed from scratch after the moves; DRC clean against this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
    [desk.kicad_pcb]
2026-08-19 Simplify enclosure cutouts to two round pigtail holes
    TB1+TB2 and TB3+TB4 each share a single off-board pigtail and are now
    fully internal, so the four wall slots (one matched to each terminal's
    wire-facing orientation) were never needed - replaced with two round
    10mm pass-throughs, one per pigtail bundle, on opposite walls.
    Corrected the antenna/USB wall assignment: pins 1/44 (antenna) are on
    the left, pins 22/23 (USB-C) on the right - the previous version had
    this backwards, putting a USB cutout on the wrong wall entirely. The
    USB slot is now a proper rounded rectangle on the right wall (the
    previous rounded_wall_slot module only rounded a 2r-wide sliver
    instead of spanning the wall's ful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
    [shell.scad, shell.stl]
2026-08-19 Fix U2 courtyard, group TB1/TB2, and shorten Q3/R2 routes
    U2's local footprint courtyard only modeled the pin-header envelope,
    not the real devkit board - it missed the antenna (~7mm past the pin
    envelope on one end) and the USB-C connector (~2.5mm on the other).
    This let TB1/TB2 get placed directly under the antenna in an earlier
    placement experiment with nothing to catch it. Extended the courtyard
    in DevKitC_2x22_P2.54mm_1in_row.kicad_mod to cover both, and refreshed
    U2 in the board from the corrected footprint.
    With that real space accounted for, relocated TB1+TB2 to sit directly
    side by side near the bottom edge (motor pair / supply pair), matching
    that they already share a single exter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
    [desk.kicad_pcb]
2026-08-19 Redesign enclosure cover as a sliding dovetail, fix wall cutout placement
    Replaces the old captured-channel sliding cover with a dovetail rail/groove
    joint (one-sided taper, endstop, resistance-based detent bump) - the channel
    design's retaining lip needed an unsupported overhang the full wall length.
    Also corrects wall cutout positions (USB slot, TB1-4 pigtail holes), which
    were placed from PCB coordinates without accounting for KiCad's Y-down
    screen convention versus a top-down 3D view's Y-up convention - verified
    directly against desk.kicad_pcb via the pcbnew Python API.
    [cover.stl, shell.scad, shell.stl]
2026-08-20 Drop the ACS724 Pololu carrier for a bare chip, draw the pigtail plugs, and clear the drawing-sheet border
    ACS724 moves from the Pololu carrier to a bare SOIC-8 chip on a generic
    SOIC-8-to-DIP-8 adapter. That drops two caps the carrier used to provide
    for free - a 0.1uF VCC bypass and a 1nF FILTER-to-GND cap, both confirmed
    against Allegro's own ACS712/ACS724 application circuit - so they're now
    discrete parts on the main board (C4, C5), placed and routed. README,
    SHOPPING_LIST.md and NETLIST.md are reconciled with the swap.
    D1 goes back to a horizontal/laid-flat DO-15 mount now that the board has
    room again, instead of the standing 2.54mm-pitch mount from the earlier
    space crunch - easier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
    [desk.kicad_pcb, desk.kicad_sch, shell.scad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]
2026-08-22 Fix TB pitch/ToF routing, renumber references, fix stale docs, implement read_current_()
    - Fix TB1-5 footprint pitch to match the actually-ordered 2.54mm Degson
    part (board previously used a 5.00mm-pitch footprint)
    - Add TB5 for a future ToF sensor's SDA/SCL, moved to GPIO38/41 after
    GPIO12/13 proved unroutable near U1's own margin; +3V3/GND for it
    shares TB2 instead of a dedicated terminal
    - Renumber every reference designator (R/C/D/Q/U/TB/J/SW) to match
    schematic reading order, closing all numbering gaps
    - Fix several stale references found along the way: leftover per-gate
    IC labels (U8/U9) in the relay-drive chain description, a fuse (F1)
    no longer fitted by design, "relay mo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
    [desk.kicad_pcb, desk.kicad_sch, shell.scad]
2026-08-26 Automate Gerber -> G-code -> Snapmaker milling pipeline
    make mill (schematics/gen/) now drives FlatCAM Evo headlessly via mill.tcl
    to isolate/drill/cutout the board, then rewrites each output through
    snapmaker_header.py so the Snapmaker A350 touchscreen doesn't crash on load
    (it requires a header with an embedded thumbnail that FlatCAM doesn't
    produce). Verified end-to-end: both the smallest and largest generated
    files load and preview correctly in Snapmaker Luban.
    Also adds tools/flatcam.sh, a launcher for the FlatCAM Evo venv install
    (tools/flatcam/, tools/flatcam-env/ - gitignored, not tracked).
2026-08-26 Fix bottom-copper mirroring, add milling registration jig, simplify drilling
    The milling pipeline had two correctness bugs that would have ruined a
    physical board: bottom copper wasn't mirrored for hand-flipping (KiCad
    exports it fab-house style, mirrored internally during lamination - not
    applicable when you flip the blank yourself), and the board wasn't
    guaranteed to land at a reproducible position for that flip. Both fixed in
    mill.tcl and verified by tracing a real copper pad's coordinates through
    the actual Gerber and G-code output, not just by inspection.
    Also: switched to a pre-cut 70x100mm blank (matching the board exactly)
    instead of an oversized sheet, removing the need for a separ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
